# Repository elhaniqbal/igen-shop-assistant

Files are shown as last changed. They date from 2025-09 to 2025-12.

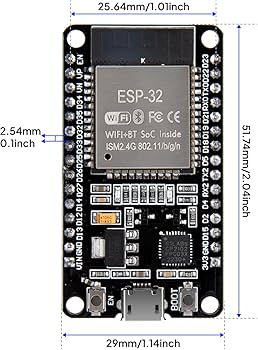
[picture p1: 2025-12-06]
electrical/igen-shop-assistant/ESP32 image.jpg

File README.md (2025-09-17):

# IGEN Smart Shop Assistant — Monorepo Scaffold (v1)

> Raspberry Pi touchscreen/web UI → **Pi Bridge (MQTT↔UART)** → **Controller MCU (ESP32-S3)** → **CAN bus** → **Cabinet MCUs (ESP32-S3)**. Postgres stores users, tools, loans; Mosquitto is the MQTT broker. This repo is an end‑to‑end template with runnable stubs.

---

## 🗂️ Repository Layout

```
igen-shop-assistant/
├─ README.md                            # Start here (you’re reading the in-repo version)
├─ CONTRIBUTING.md
├─ .gitignore
├─ .github/ (LATER DOWN THE ROAD)
│  ├─ workflows/
│  │  ├─ ci.yml                         # Lint, typecheck, build stubs
│  │  └─ pre-commit.yml
│  └─ ISSUE_TEMPLATE.md
├─ docs/
│  ├─ system-overview.md                # Diagrams + deep dives
│  ├─ comms-topology.md                 # MQTT & CAN topics/IDs
│  ├─ onboarding.md                     # Short onboarding for new devs
│  └─ troubleshooting.md
├─ env/
│  ├─ .env.example                      # Copy to .env (root)
│  └─ secrets.template.md
├─ deploy/ (OPTIONAL FOR NOW)
│  ├─ docker-compose.yml                # Mosquitto, Postgres, Adminer, Backend
│  ├─ mosquitto/
│  │  ├─ mosquitto.conf
│  │  └─ aclfile
│  └─ postgres/
│     └─ init.sql                       # DB schema + seed
├─ services/ (RUNS ON RASPBERRY PI)
│  ├─ backend-fastapi/                  # API + events processor (MQTT↔DB)
│  │  ├─ pyproject.toml
│  │  ├─ app/
│  │  │  ├─ main.py                     # FastAPI app
│  │  │  ├─ deps.py                     # DB & MQTT wiring
│  │  │  ├─ models.py                   # SQLModel ORM
│  │  │  ├─ schemas.py                  # Pydantic (JSON/CBOR contracts)
│  │  │  ├─ mqtt_handlers.py            # Subscriptions/handlers
│  │  │  └─ routes/
│  │  │     ├─ admin.py
│  │  │     └─ student.py
│  │  └─ tests/
│  ├─ pi-bridge/                        # Runs on Raspberry Pi (MQTT↔UART)
│  │  ├─ pyproject.toml
│  │  └─ bridge/
│  │     ├─ main.py                     # Sub MQTT, frame CBOR, send over UART
│  │     ├─ uart.py
│  │     └─ framing.py                  # SLIP-like framing + checksum
│  └─ mock-ui-cli/                      # Temporary CLI to simulate the UI
│     ├─ package.json
│     └─ src/
│        └─ index.ts
├─ firmware/
│  ├─ platformio.ini
│  ├─ lib/
│  │  ├─ CanFrame/
│  │  │  ├─ CanFrame.h
│  │  │  └─ CanFrame.cpp
│  │  └─ MsgPack/
│  │     ├─ Msg.h
│  │     └─ Msg.cpp
│  ├─ controller-mcu/                   # ESP32-S3 (UART↔CAN)
│  │  ├─ src/
│  │  │  └─ main.cpp
│  │  └─ include/
│  └─ cabinet-mcu/                      # ESP32-S3 (CAN + IO + sensors)
│     ├─ src/
│     │  └─ main.cpp
│     └─ include/
├─ shared/
│  ├─ schemas/                          # JSON/CBOR schemas with examples
│  │  ├─ mqtt/
│  │  │  ├─ dispense_request.schema.json
│  │  │  ├─ dispense_result.schema.json
│  │  │  ├─ heartbeat.schema.json
│  │  │  └─ sensor_update.schema.json
│  │  └─ can/
│  │     └─ id_format.md                # 11-bit layout + table
│  └─ proto/                            # (optional) for gRPC later
└─ tools/
   ├─ scripts/
   │  ├─ seed_tools.py
   │  └─ gen_test_data.py
   └─ git-templates/
      └─ commit-msg                     # Enforce Conventional Commits
```

---

## 🔐 Branching & Protection (GitHub)

1. **Default branch:** `main`.
2. **Branch naming:** `<your-name>/<type>-<short-desc>` e.g. `elhan/feat-dispense-flow`.
3. **Conventional Commits:** `feat:`, `fix:`, `docs:`, `refactor:`, etc.
4. **Require PR reviews:** At least **1** approval; disallow self-merge.
5. **Require up to date:** Rebase or merge from `main` before merge.

---

## 🧠 System Contracts (Topics, Payloads, CAN IDs)

### MQTT Topic Namespace (broker = Mosquitto)

* Commands from UI/backend → Controller:

  * **`shop/cmd/dispense`** (QoS1): request a dispense action
  * **`shop/cmd/cancel`** (QoS1)
* Controller/MCUs → Backend (events):

  * **`shop/evt/dispense_result`** (QoS1)
  * **`shop/evt/sensor_update`** (QoS0)
  * **`shop/evt/heartbeat`** (QoS0, retain last)
* Device state:

  * **`shop/state/controller`** (retain)
  * **`shop/state/cabinet/{cabinet_id}`** (retain)

> Payloads use **JSON** for human readability during dev; CBOR over **UART** and **CAN** for compactness on microcontrollers.

#### `dispense_request` (JSON)

```json
{
  "request_id": "uuid4",
  "student": { "ubc_card_uid": "hex", "student_id": "string" },
  "items": [ { "tool_id": "uuid", "qty": 1, "slot_id": "CAB01-S05" } ],
  "loan_days": 7,
  "limit_policy": { "max_tools": 3 },
  "requested_at": "2025-09-17T19:00:00Z"
}
```

#### `dispense_result` (JSON)

```json
{
  "request_id": "uuid4",
  "status": "OK | DENIED | PARTIAL | ERROR",
  "details": [ { "slot_id": "CAB01-S05", "result": "OK|JAM|EMPTY" } ],
  "controller_time": "2025-09-17T19:00:01Z"
}
```

#### `heartbeat` (JSON)

```json
{ "device": "controller|cabinet", "id": "CAB01", "ts": "2025-09-17T19:00:00Z", "uptime_s": 1234 }
```

> CBOR equivalents are produced/consumed by Pi Bridge (UART) and MCUs (CAN). See `shared/schemas/` for full drafts.

### CAN ID Layout (11-bit standard)

```
[10..9] Priority (2b)   00=high 01=med 10=low 11=dbg
[8..5]  MsgType  (4b)   0=HB 1=CMD 2=ACK 3=SENS 4=ERR ...
[4..0]  NodeID   (5b)   0=controller, 1..30=cabinets, 31=broadcast
```

**Examples:**

* Broadcast heartbeat from controller: `Prio=10, Type=HB=0x0, Node=0` → `0b10_0000_00000` = `0x200`
* Command to Cabinet #5: `Prio=01, Type=CMD=0x1, Node=0x05` → `0b01_0001_00101` = `0x125`

---

## 🧱 Database (Postgres) — Minimal Schema

`deploy/postgres/init.sql` seeds:

```sql
CREATE EXTENSION IF NOT EXISTS "uuid-ossp";

CREATE TABLE students (
  id UUID PRIMARY KEY DEFAULT uuid_generate_v4(),
  student_id TEXT UNIQUE NOT NULL,
  ubc_card_uid TEXT UNIQUE,
  name TEXT,
  email TEXT,
  created_at TIMESTAMPTZ DEFAULT now()
);

CREATE TABLE tools (
  id UUID PRIMARY KEY DEFAULT uuid_generate_v4(),
  name TEXT NOT NULL,
  sku TEXT,
  description TEXT,
  created_at TIMESTAMPTZ DEFAULT now()
);

CREATE TABLE inventory_slots (
  id TEXT PRIMARY KEY,              -- e.g., CAB01-S05
  cabinet_id TEXT NOT NULL,         -- e.g., CAB01
  tool_id UUID REFERENCES tools(id),
  capacity INT NOT NULL DEFAULT 1,
  qty INT NOT NULL DEFAULT 0,
  sensor_type TEXT,                 -- ir, weight, switch
  created_at TIMESTAMPTZ DEFAULT now()
);

CREATE TABLE loans (
  id UUID PRIMARY KEY DEFAULT uuid_generate_v4(),
  student_id UUID REFERENCES students(id),
  tool_id UUID REFERENCES tools(id),
  slot_id TEXT REFERENCES inventory_slots(id),
  qty INT NOT NULL,
  requested_at TIMESTAMPTZ DEFAULT now(),
  due_at TIMESTAMPTZ NOT NULL,
  returned_at TIMESTAMPTZ
);

CREATE TABLE events (
  id BIGSERIAL PRIMARY KEY,
  kind TEXT NOT NULL,               -- dispense_result, sensor_update, heartbeat
  body JSONB NOT NULL,
  created_at TIMESTAMPTZ DEFAULT now()
);

-- Limits view (example): how many active loans per student
CREATE VIEW active_loan_counts AS
SELECT student_id, COUNT(*) AS active
FROM loans WHERE returned_at IS NULL
GROUP BY student_id;
```

---

## 🐋 Dev Stack (Docker Compose)

`deploy/docker-compose.yml`

```yaml
version: "3.9"
services:
  mqtt:
    image: eclipse-mosquitto:2
    ports: ["1883:1883", "9001:9001"]
    volumes:
      - ./mosquitto/mosquitto.conf:/mosquitto/config/mosquitto.conf
      - ./mosquitto/aclfile:/mosquitto/config/aclfile
  db:
    image: postgres:16
    environment:
      POSTGRES_PASSWORD: postgres
      POSTGRES_USER: postgres
      POSTGRES_DB: shop
    ports: ["5432:5432"]
    volumes:
      - dbdata:/var/lib/postgresql/data
      - ./postgres/init.sql:/docker-entrypoint-initdb.d/init.sql
  adminer:
    image: adminer
    ports: ["8080:8080"]
  backend:
    build: ../services/backend-fastapi
    env_file: ../env/.env
    depends_on: [mqtt, db]
    command: uvicorn app.main:app --host 0.0.0.0 --port 8000
    ports: ["8000:8000"]
volumes:
  dbdata:
```

`deploy/mosquitto/mosquitto.conf`

```conf
listener 1883 0.0.0.0
allow_anonymous true
persistence true
```

---

## 🧩 Backend (FastAPI) — MQTT↔DB glue

`services/backend-fastapi/app/schemas.py`

```python
from pydantic import BaseModel, Field
from typing import List, Literal, Optional
import uuid

class Student(BaseModel):
    ubc_card_uid: str
    student_id: str

class DispenseItem(BaseModel):
    tool_id: str
    qty: int = 1
    slot_id: str

class DispenseRequest(BaseModel):
    request_id: str = Field(default_factory=lambda: str(uuid.uuid4()))
    student: Student
    items: List[DispenseItem]
    loan_days: int = 7
    limit_policy: dict = {"max_tools": 3}

class DispenseDetail(BaseModel):
    slot_id: str
    result: Literal["OK", "JAM", "EMPTY", "DENIED", "ERROR"]

class DispenseResult(BaseModel):
    request_id: str
    status: Literal["OK", "DENIED", "PARTIAL", "ERROR"]
    details: List[DispenseDetail]
```

`services/backend-fastapi/app/main.py`

```python
from fastapi import FastAPI, Depends
from app.schemas import DispenseRequest
from app.mqtt_handlers import publish_dispense

app = FastAPI(title="Shop Assistant Backend")

@app.post("/api/dispense")
def create_dispense(req: DispenseRequest):
    # TODO: validate limits against DB
    publish_dispense(req)
    return {"ok": True, "request_id": req.request_id}
```

`services/backend-fastapi/app/mqtt_handlers.py`

```python
import json, os
import paho.mqtt.client as mqtt
from app.schemas import DispenseRequest

MQTT_HOST = os.getenv("MQTT_HOST", "localhost")
TOPIC_CMD_DISPENSE = "shop/cmd/dispense"

_client = mqtt.Client(mqtt.CallbackAPIVersion.VERSION2)
_client.connect(MQTT_HOST, 1883, 60)

def publish_dispense(req: DispenseRequest):
    _client.publish(TOPIC_CMD_DISPENSE, json.dumps(req.model_dump()), qos=1)
```

---

## 🔗 Pi Bridge (MQTT↔UART, CBOR framing)

`services/pi-bridge/bridge/framing.py`

```python
import cbor2, zlib

START = b"\xC0"  # SLIP-like sentinel

def encode_frame(obj: dict) -> bytes:
    payload = cbor2.dumps(obj)
    crc = zlib.crc32(payload) & 0xFFFFFFFF
    body = payload + crc.to_bytes(4, "big")
    return START + body + START

def decode_frames(buf: bytes):
    # naive splitter for demo
    parts = buf.split(START)
    for i in range(1, len(parts)-1):
        body = parts[i]
        payload, crc = body[:-4], int.from_bytes(body[-4:], "big")
        if zlib.crc32(payload) & 0xFFFFFFFF == crc:
            yield cbor2.loads(payload)
```

`services/pi-bridge/bridge/main.py`

```python
import json, os, serial, threading
import paho.mqtt.client as mqtt
from .framing import encode_frame, decode_frames

MQTT_HOST = os.getenv("MQTT_HOST", "localhost")
UART_PORT = os.getenv("UART_PORT", "/dev/ttyUSB0")
UART_BAUD = int(os.getenv("UART_BAUD", "115200"))

TOPIC_CMD_DISPENSE = "shop/cmd/dispense"
TOPIC_EVT_RESULT   = "shop/evt/dispense_result"

ser = serial.Serial(UART_PORT, UART_BAUD, timeout=0.1)
client = mqtt.Client(mqtt.CallbackAPIVersion.VERSION2)
client.connect(MQTT_HOST, 1883, 60)

# MQTT→UART
def on_message(_c, _ud, msg):
    if msg.topic == TOPIC_CMD_DISPENSE:
        payload = json.loads(msg.payload)
        frame = encode_frame({"t":"DISPENSE", "d": payload})
        ser.write(frame)

client.on_message = on_message
client.subscribe([(TOPIC_CMD_DISPENSE, 1)])
client.loop_start()

# UART→MQTT (controller responses)
rx_buf = bytearray()

def uart_rx_loop():
    while True:
        rx = ser.read(512)
        if rx:
            rx_buf.extend(rx)
            for obj in decode_frames(bytes(rx_buf)):
                if obj.get("t") == "DISPENSE_RESULT":
                    client.publish(TOPIC_EVT_RESULT, json.dumps(obj["d"]))
            # simple: clear buffer on parse attempt
            rx_buf.clear()

threading.Thread(target=uart_rx_loop, daemon=True).start()

print("Pi Bridge running.")
```

---

## 🔧 Firmware — Controller MCU (ESP32-S3, UART↔CAN)

`firmware/platformio.ini`

```ini
[env:esp32s3]
platform = espressif32 @ 6.6.0
board = esp32-s3-devkitc-1
framework = arduino
monitor_speed = 115200
lib_deps =
  adafruit/Adafruit MCP2515 @ ^1.1.0   ; example CAN via MCP2515 if using external transceiver
  bblanchon/ArduinoJson @ ^7
```

`firmware/lib/CanFrame/CanFrame.h`

```cpp
#pragma once
#include <Arduino.h>
struct CanMsg { uint16_t id; uint8_t len; uint8_t data[8]; };
uint16_t makeId(uint8_t prio, uint8_t type, uint8_t node);
```

`firmware/lib/CanFrame/CanFrame.cpp`

```cpp
#include "CanFrame.h"
uint16_t makeId(uint8_t prio, uint8_t type, uint8_t node){
  return ((prio & 0x3) << 9) | ((type & 0xF) << 5) | (node & 0x1F);
}
```

`firmware/controller-mcu/src/main.cpp`

```cpp
#include <Arduino.h>
#include <ArduinoJson.h>
#include "CanFrame.h"

// TODO: init CAN driver (MCP2515 or built-in TWAI for ESP32)

static String rxBuf;

void sendDispenseToCabinet(const JsonObject& req){
  // naive: send one frame per item to its cabinet node
  for (JsonObject item : req["items"].as<JsonArray>()){
    String slot = item["slot_id"].as<String>(); // e.g., CAB01-S05
    uint8_t cabinet = (uint8_t) slot.substring(3,5).toInt(); // "01" -> 1
    uint8_t node = cabinet; // node id mapping

    uint16_t id = makeId(1, /*CMD*/1, node);
    uint8_t data[8] = { 'D','S','P', (uint8_t)item["qty"].as<int>(), 0,0,0,0 };
    // TODO: pack better (CBOR/msgpack)
    // canSend({ .id=id, .len=8, .data={...}});
  }
}

void setup(){
  Serial.begin(115200);
  // canInit();
}

void loop(){
  while (Serial.available()){
    char c = (char)Serial.read();
    rxBuf += c;
    if (c == '\xC0'){
      // demo: parse very simply assuming one JSON frame between 0xC0 sentinels
      int s = rxBuf.indexOf('\xC0');
      int e = rxBuf.lastIndexOf('\xC0');
      if (e > s){
        String body = rxBuf.substring(s+1, e);
        StaticJsonDocument<1024> doc;
        if (deserializeJson(doc, body) == DeserializationError::Ok){
          const char* t = doc["t"];
          if (strcmp(t, "DISPENSE") == 0){
            JsonObject d = doc["d"].as<JsonObject>();
            sendDispenseToCabinet(d);
            // respond minimal result
            StaticJsonDocument<256> res;
            res["t"] = "DISPENSE_RESULT";
            JsonObject dd = res.createNestedObject("d");
            dd["request_id"] = d["request_id"].as<const char*>();
            dd["status"] = "OK";
            serializeJson(res, Serial);
            Serial.write('\xC0');
          }
        }
        rxBuf = "";
      }
    }
  }
  // TODO: forward CAN sensor/heartbeat upstream periodically
}
```

---

## 🔩 Firmware — Cabinet MCU (ESP32-S3, CAN + IO)

`firmware/cabinet-mcu/src/main.cpp`

```cpp
#include <Arduino.h>
#include "CanFrame.h"

const int SOLENOID_PIN = 10; // example
const int IR_PIN = 4;        // example
uint8_t NODE_ID = 1;         // set uniquely per cabinet

void setup(){
  pinMode(SOLENOID_PIN, OUTPUT);
  pinMode(IR_PIN, INPUT_PULLUP);
  // canInit(node=NODE_ID)
}

void loop(){
  // if (canAvailable()){
  //   CanMsg m = canRead();
  //   uint8_t type = (m.id >> 5) & 0xF;
  //   if (type == 1 /*CMD*/){
  //     // naive: data[0..2] == 'D','S','P'
  //     digitalWrite(SOLENOID_PIN, HIGH);
  //     delay(500);
  //     digitalWrite(SOLENOID_PIN, LOW);
  //   }
  // }

  // heartbeat every 2s (pseudo)
  // static uint32_t last=0; if (millis()-last>2000){ sendHB(); last=millis(); }
}
```

---

## 🧪 Mock UI (CLI) — temporary student/admin flows

`services/mock-ui-cli/src/index.ts`

```ts
import mqtt from 'mqtt';
import { randomUUID } from 'crypto';

const client = mqtt.connect('mqtt://localhost:1883');

function sendDispense(studentId: string, cardUid: string, slotId: string, toolId: string){
  const payload = {
    request_id: randomUUID(),
    student: { student_id: studentId, ubc_card_uid: cardUid },
    items: [{ tool_id: toolId, qty: 1, slot_id: slotId }],
    loan_days: 7,
    limit_policy: { max_tools: 3 }
  };
  client.publish('shop/cmd/dispense', JSON.stringify(payload), { qos: 1 });
  console.log('sent dispense', payload);
}

client.on('connect', () => {
  console.log('CLI connected to MQTT');
  sendDispense('s12345678', 'ABCD1234', 'CAB01-S05', 'tool-uuid-1');
});

client.on('message', (t, m) => console.log('evt', t, m.toString()));
client.subscribe('shop/evt/#');
```

---

## 🪪 Card Scanning (abstracted)

On Pi, you can plug a USB NFC reader (ACR122U). Add a `card-reader` module later; for now we provide an **interface** and a **mock** used by the CLI or UI.

Interface (Python):

```python
# services/backend-fastapi/app/card_reader.py
from typing import Optional
class CardReader:
    def get_uid(self) -> Optional[str]:
        """Return hex UID if a card is present else None."""
        raise NotImplementedError

class MockCardReader(CardReader):
    def __init__(self, fixed_uid: str = "ABCD1234"): self.fixed = fixed_uid
    def get_uid(self) -> Optional[str]: return self.fixed
```

---

## 🧭 E2E Flow (What talks to what?)

1. **Student/Admin UI** (web or touchscreen) calls **`POST /api/dispense`** with tool list + card UID.
2. **Backend** validates limits (DB), then publishes **`shop/cmd/dispense`** (JSON).
3. **Pi Bridge** subscribes; converts JSON→CBOR, frames, sends over **UART** to **Controller MCU**.
4. **Controller** parses, maps items → target **Cabinet NodeIDs**, pushes **CMD** frames on **CAN**.
5. **Cabinet MCU** executes (opens solenoid, etc.), optionally reads **IR** to confirm removal, replies via **ACK/SENS**.
6. **Controller** aggregates results → emits **DISPENSE\_RESULT** back over **UART**.
7. **Pi Bridge** publishes **`shop/evt/dispense_result`** (JSON) to MQTT.
8. **Backend** records event & creates **loan** rows (due date = now + loan\_days). Admin notifications (later).

---

## 🚀 Quickstart (Dev)

```bash
# 0) Clone & setup
cp env/.env.example .env
pre-commit install

# 1) Infra
cd deploy && docker compose up -d  # mqtt, postgres, adminer, backend

# 2) Mock UI (simulates student flow)
cd services/mock-ui-cli && npm i && npm run start

# 3) Pi Bridge (if you have a USB-Serial to controller)
cd services/pi-bridge && uv sync && UV_HTTP_TIMEOUT=60 python -m bridge.main
# (set UART_PORT in .env)

# 4) Firmware
# Open `firmware/` in VSCode + PlatformIO, flash controller & a cabinet
```

---

## ✅ Contribution Rules (TL;DR)

* Branch from `main` → name it like `elhan/feat-can-heartbeat`.
* Small PRs with checklists.
* Update `docs/` if you change comms or schemas.
* Add tests where possible (unit tests for handlers, framing, id pack/unpack).
* Keep **topics** and **CAN IDs** in sync with `docs/comms-topology.md`.

---

## 📄 Appendix — Samples & Stubs

**`shared/schemas/mqtt/heartbeat.schema.json`**

```json
{
  "$schema": "https://json-schema.org/draft/2020-12/schema",
  "$id": "https://ubc.example/schemas/heartbeat.json",
  "type": "object",
  "properties": {
    "device": {"enum": ["controller", "cabinet"]},
    "id": {"type": "string"},
    "ts": {"type": "string", "format": "date-time"},
    "uptime_s": {"type": "integer", "minimum": 0}
  },
  "required": ["device", "id", "ts", "uptime_s"]
}
```

**`docs/comms-topology.md`**

```md
# Comms Topology

- UART framing: SLIP-like 0xC0 sentinels, CBOR payload + CRC32.
- CAN: 11-bit IDs (prio|type|node). Data: small msgpack/CBOR blobs.
- Heartbeat: controller every 2s (broadcast), cabinet every 5s.
- Timeouts: dispense op must return within 5s else mark PARTIAL.
```

---

## 🧯 Troubleshooting Cheats

* Nothing on MQTT? `mosquitto_sub -t '#' -v -h localhost`
* UART garbage? Check baud and USB device; ensure `C0` framing matches both sides.
* CAN silent? Verify 120Ω termination at bus ends and common GND.
* DB empty? Open Adminer at [http://localhost:8080](http://localhost:8080) and confirm `tools` seeded.

---

## 📌 Roadmap to v2

* Real NFC reader module (ACR122U) integration on Pi.
* Policy engine for loan limits and overdue alerts.
* Proper CAN driver config (TWAI) and message packing.
* Migrate JSON payloads to CBOR end‑to‑end when UI tooling ready.
* Web UI (Next.js) for Admin/Student dashboards.

```
```

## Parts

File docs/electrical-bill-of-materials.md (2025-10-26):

| Type | Component | Role (what/why) | Qty | Unit est (CAD) | Link (example) |
| --- | --- | --- | ----: | ---: | --- |
| **Static**  | 24 V DC PSU (200–350 W) | Main DC backbone for actuators & logic | 1 | 50 | [MeanWell LRS-350-48](https://www.digikey.ca/en/products/detail/mean-well-usa-inc/LRS-350-48/7705033) |
| **Static**  | IEC inlet w/ switch + fuse | Safe AC entry, master power | 1 | 10 | [uxcell IEC 320 C14](https://www.amazon.ca/uxcell%C2%AE-Terminals-Panel-Socket-Connector/dp/B00HUHAB0U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) |
| **Static**  | EMI line filter | Suppress mains noise | 1 | 10 | [Schaffner FN9222](https://www.digikey.ca/en/products/detail/te-connectivity-schaffner/FN9222-1-06/1928997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) |
| **Static**  | Main breaker/fuse | Overcurrent protection | 1 | 18 | [AWG fuse holder (5pack)](https://www.amazon.ca/gp/product/B0B3J33H38/ref=ox_sc_act_image_1?smid=A3NON9NCBFQHD7&th=1) |
| **Static**  | Terminal Block | Power distribution | 1 set | 15 | [Random Amazon Terminal Block](https://www.amazon.com/Joinfworld-Position-Terminal-Pre-Insulated-Jumper/dp/B0BVR4VY1J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) |
| **Static**  | 24 V TVS diodes | Surge/inductive kick protection | 2 | 4 | [SMBJ24A](https://www.digikey.ca/en/products/detail/littelfuse-inc/SMBJ24A/656394) | |
| **Static**  | Wire + ferrules + glands | Harnessing consumables |  bulk | 25 | [Wire kit](https://www.amazon.ca/582-piece-Electrical-Terminal-Connector-Stripper/dp/B077YZJGQ2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) |
| **Static**  | E-stop switch | Safety cut to PSU | 1 | 12 | [22 mm mushroom NC](https://www.amazon.ca/RuoFeng-Mushroom-Emergency-Button-Switch/dp/B07HBN45Q9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) |
| **Static**  | Branch fuse holders | Per-cabinet protection | n | 15 | [DIN mini fuse](https://www.amazon.ca/KOLACEN-Automotive-Assorted-Circuit-Adapter/dp/B08LTJFBHX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) |
| **Static**  | RFID reader (MFRC522) | User login at kiosk | 1 | 25| [MFRC522 kit](https://leeselectronic.com/en/product/15157-rfid-mifare-rc522-reader-breakout-w-receiver-key.html) |
| **Static**  | RFID chips | IDs for users/tools | 1 | 23| [NTAG213 chips](https://www.amazon.ca/Rewritable-Stickers-Adhesive-Programmable-Compatible/dp/B0C2YW4RM8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) |
| **Dynamic** | 24→5 V buck (3–5 A) | Cabinet logic/sensor rail | n | 13 | [LM2596 buck module](https://www.amazon.ca/Regulator-Adjustable-Converter-Electronic-Stabilizer/dp/B07PDGG84B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) |
| **Dynamic** | CAN transceiver (SN65HVD230) | Node comms to bus | n | 12 | [SN65HVD230 board](https://www.amazon.ca/Waveshare-SN65HVD230-CAN-Board-Communication/dp/B0B5DTN62K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) | | |
| **Dynamic** | Microswitch/IR sensor strip  | Detect slicer | n | 1 | [Micro switch pack](https://www.amazon.ca/Gebildet-pieces-Momentary-Action-V-156-1C25/dp/B07T9DWV4J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) |
| **Static** | Connectors/pigtails | Wiring I/O in cabinet | 1 set | 43 | [JST-VH kit](https://www.amazon.ca/Preciva-Connector-AWG28-18%EF%BC%880-08-1mm%C2%B2-Ratcheting-terminals/dp/B0CH7SB4PC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) |
| **Dynamic** | AS5600 Magnetic Encoder | Angle sensor | n | 6  | [A5600 Encoder](https://www.amazon.ca/Liyquint-Precision-AS5600-Induction-Measurement/dp/B0DQNQTDBT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)
| **Dynamic** | TMC2208 Stepper Driver | Motor Driver for Nema 17 | n | 5  | [TMC2208](https://www.amazon.ca/DKARDU-TMC2208-Adjustable-Screwdriver-Controller/dp/B0CD2CMR65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)

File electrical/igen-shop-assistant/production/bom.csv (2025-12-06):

Designator | Footprint | Quantity | Value | LCSC Part #
24VIN1 | TerminalBlock_Phoenix_MKDS-1,5-2_1x02_P5.00mm_Horizontal | 1 | Conn_01x02 | C8465
AS5600, MOTOR1, SN65HVD230 | PinSocket_1x04_P2.54mm_Horizontal | 3 | Conn_01x04_Socket | C22373928
C1 | 1210 | 1 | 2.2uF | C55151
C2 | 1210 | 1 | 0.1uF | C527381
C3, C8 | 1210 | 2 | 22uF | C309062
C7 | 0603 | 1 | 75pF | C282074
CBOOT2 | 0805 | 1 | 100n | C49678
J1, J2 | PinSocket_1x15_P2.54mm_Vertical | 2 | Conn_01x15_Socket | C41417327
L1 | L_10.4x10.4_H4.8 | 1 | 10uH | C9185
R10 | 0603 | 1 | 100k | C14675
R2 | 0603 | 1 | 511k | C861454
R5 | 0603 | 1 | 105k | C861072
R7 | 0603 | 1 | 2k | C22975
R8 | 0603 | 1 | 22.1k | C25961
R9 | 0603 | 1 | 49.9 | C23185
SWITCH/SENSOR | PinSocket_1x03_P2.54mm_Horizontal | 1 | Conn_01x03_Socket | C22373927
TMC2208_IO1, TMC2208_PWR1 | PinSocket_1x08_P2.54mm_Vertical | 2 | Conn_01x08_Socket | C27438
U1 | SOT-23-6 | 1 | TPS54308 | C168839

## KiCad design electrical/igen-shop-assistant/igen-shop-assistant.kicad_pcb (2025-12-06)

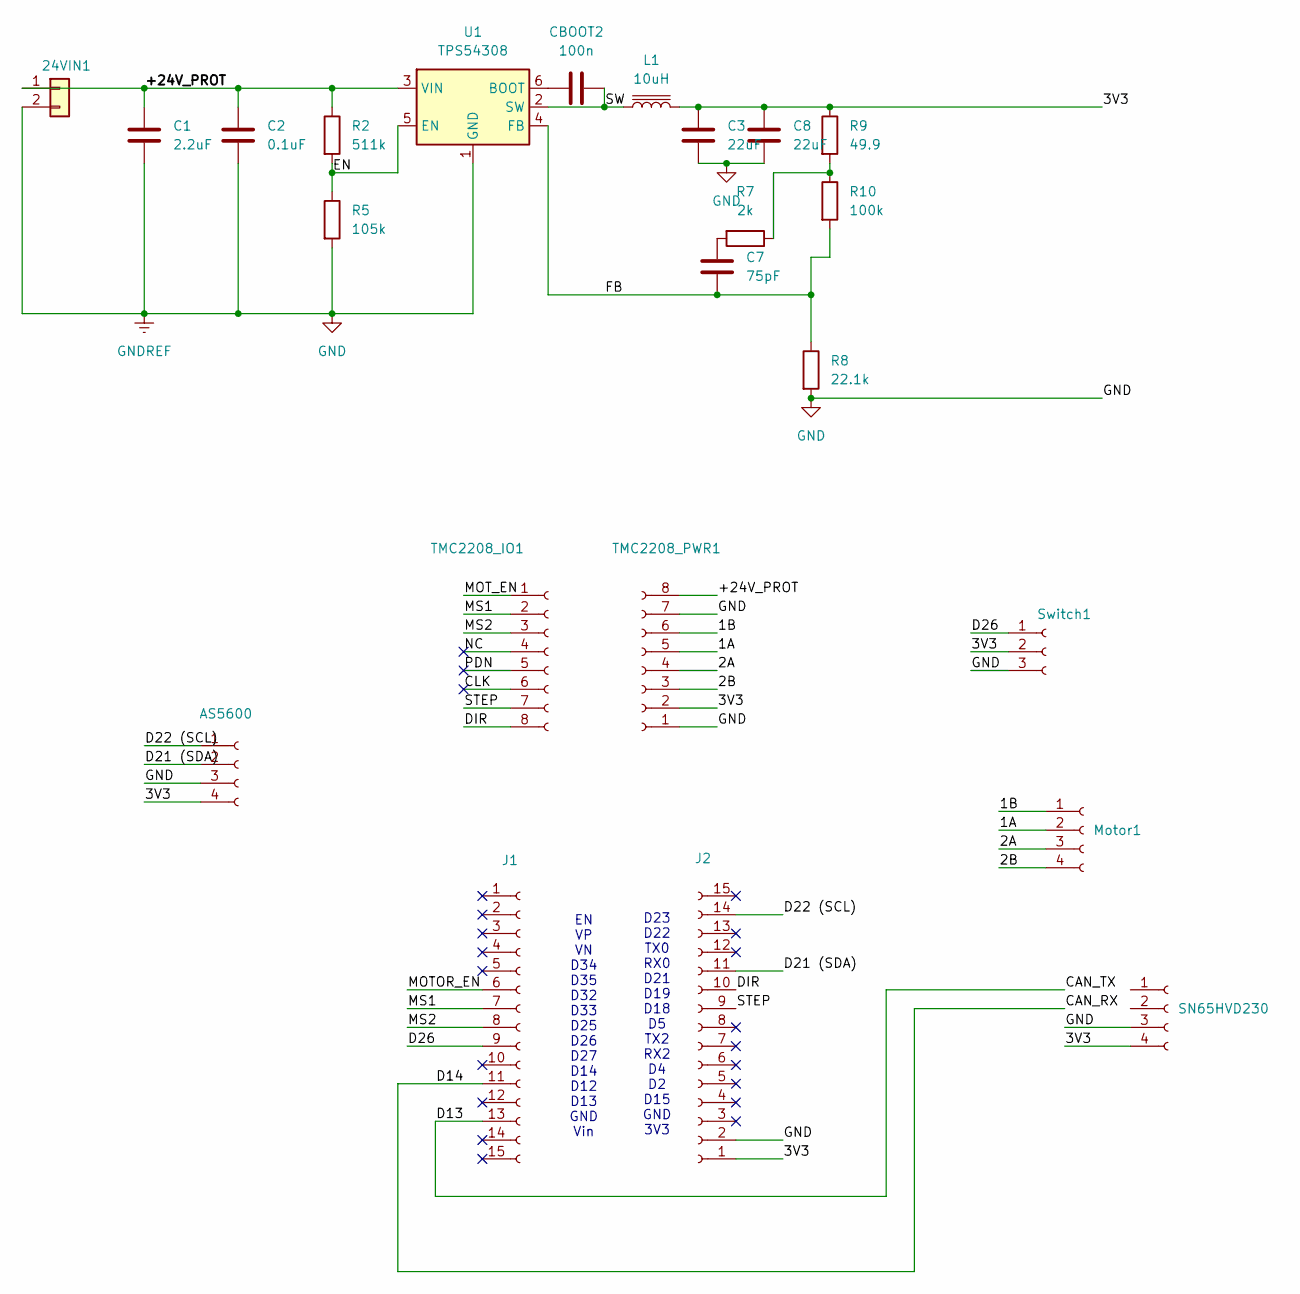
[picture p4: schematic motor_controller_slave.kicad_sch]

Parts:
24VIN1: Conn_01x02; TerminalBlock_Phoenix_MKDS-1,5-2_1x02_P5.00mm_Horizontal; JLCPCB Part Number C8465
AS5600: Conn_01x04_Socket; PinSocket_1x04_P2.54mm_Horizontal; JLCPCB Part Number C22373928
C1: 2.2uF; C_1210_3225Metric; JLCPCB Part Number C55151
C2: 0.1uF; C_1210_3225Metric; JLCPCB Part Number C527381
C3, C8: 22uF; C_1210_3225Metric; JLCPCB Part Number C309062
C7: 75pF; C_0603_1608Metric; JLCPCB Part Number C282074
CBOOT2: 100n; C_0805_2012Metric; JLCPCB Part Number C49678
J1, J2: Conn_01x15_Socket; PinSocket_1x15_P2.54mm_Vertical; JLCPCB Part Number C41417327
L1: 10uH; L_10.4x10.4_H4.8; JLCPCB Part Number C9185
Motor1: Conn_01x04_Socket; PinSocket_1x04_P2.54mm_Horizontal; JLCPCB Part Number C22373928
R2: 511k; R_0603_1608Metric; JLCPCB Part Number C861454
R5: 105k; R_0603_1608Metric; JLCPCB Part Number C861072
R7: 2k; R_0603_1608Metric; JLCPCB Part Number C22975
R8: 22.1k; R_0603_1608Metric; JLCPCB Part Number C25961
R9: 49.9; R_0603_1608Metric; JLCPCB Part Number C23185
R10: 100k; R_0603_1608Metric; JLCPCB Part Number C14675
SN65HVD230: Conn_01x04_Socket; PinSocket_1x04_P2.54mm_Horizontal; JLCPCB Part Number C22373928
Switch1: Conn_01x03_Socket; PinSocket_1x03_P2.54mm_Horizontal; JLCPCB Part Number C22373927
TMC2208_IO1, TMC2208_PWR1: Conn_01x08_Socket; PinSocket_1x08_P2.54mm_Vertical; JLCPCB Part Number C27438
U1: TPS54308; SOT-23-6; JLCPCB Part Number C168839

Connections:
/ESP32+CAN+TMC2208/1A: Motor1.2, TMC2208_PWR1.5
/ESP32+CAN+TMC2208/1B: Motor1.1, TMC2208_PWR1.6
/ESP32+CAN+TMC2208/2A: Motor1.3, TMC2208_PWR1.4
/ESP32+CAN+TMC2208/2B: Motor1.4, TMC2208_PWR1.3
/ESP32+CAN+TMC2208/3V3: AS5600.4, C3.1, C8.1, J2.1, L1.2, R9.1, SN65HVD230.4, Switch1.2, TMC2208_PWR1.2; also elsewhere on the board
/ESP32+CAN+TMC2208/+24V_PROT: 24VIN1.1, C1.1, C2.1, R2.1, TMC2208_PWR1.8, U1.3 (VIN)
/ESP32+CAN+TMC2208/CAN_RX: J1.11
/ESP32+CAN+TMC2208/CAN_TX: J1.13
/ESP32+CAN+TMC2208/CLK: TMC2208_IO1.6
/ESP32+CAN+TMC2208/D21 (SDA): AS5600.2, J2.11
/ESP32+CAN+TMC2208/D22 (SCL): AS5600.1, J2.14
/ESP32+CAN+TMC2208/D26: J1.9, Switch1.1; also elsewhere on the board
/ESP32+CAN+TMC2208/DIR: J2.10, TMC2208_IO1.8
/ESP32+CAN+TMC2208/EN: R2.2, R5.1, U1.5 (EN)
/ESP32+CAN+TMC2208/FB: C7.2, R8.1, R10.2, U1.4 (FB)
/ESP32+CAN+TMC2208/MOTOR_EN: J1.6
/ESP32+CAN+TMC2208/MOT_EN: TMC2208_IO1.1
/ESP32+CAN+TMC2208/MS1: J1.7, TMC2208_IO1.2
/ESP32+CAN+TMC2208/MS2: J1.8, TMC2208_IO1.3
/ESP32+CAN+TMC2208/NC: TMC2208_IO1.4
/ESP32+CAN+TMC2208/PDN: TMC2208_IO1.5
/ESP32+CAN+TMC2208/STEP: J2.9, TMC2208_IO1.7
/ESP32+CAN+TMC2208/SW: CBOOT2.2, L1.1, U1.2 (SW)
GND: 24VIN1.2, AS5600.3, C1.2, C2.2, C3.2, C8.2, J2.2, R5.2, R8.2, SN65HVD230.3, Switch1.3, TMC2208_PWR1.1, TMC2208_PWR1.7, U1.1 (GND); also elsewhere on the board
unnamed: C7.1, R7.2
unnamed: R7.1, R9.2, R10.1
unnamed: CBOOT2.1, U1.6 (BOOT)

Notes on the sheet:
EN VP VN D34 D35 D32 D33 D25 D26 D27 D14 D12 D13 GND Vin
D23 D22 TX0 RX0 D21 D19 D18 D5 TX2 RX2 D4 D2 D15 GND 3V3

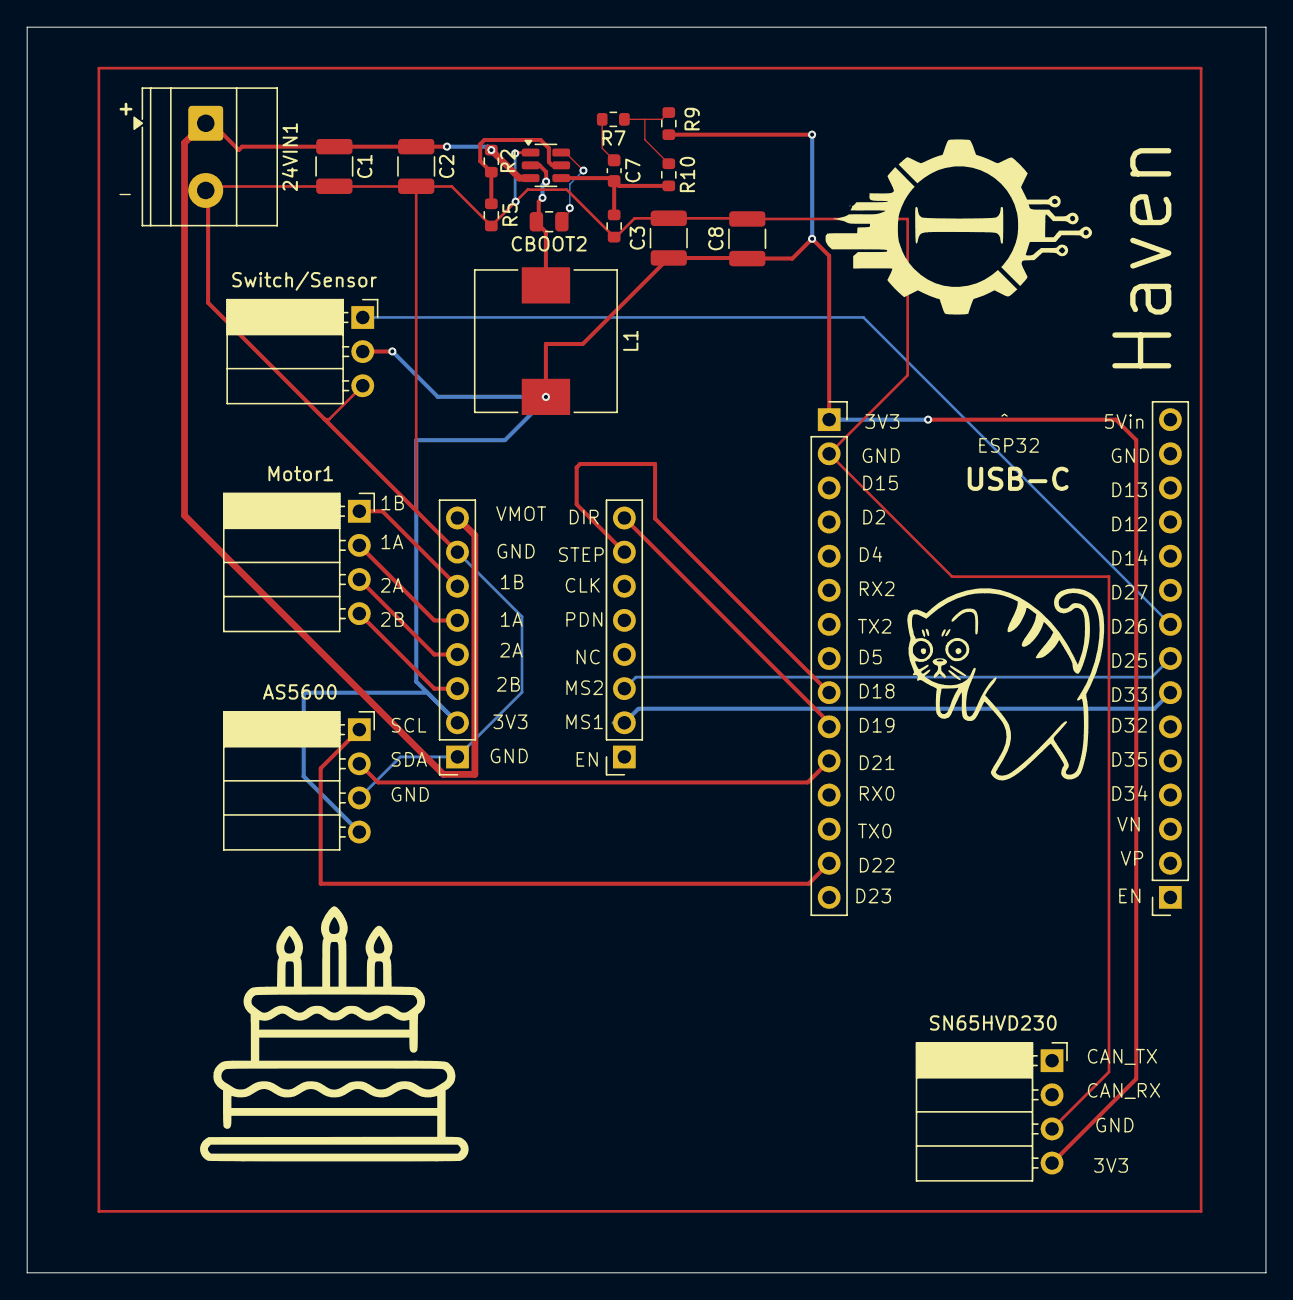
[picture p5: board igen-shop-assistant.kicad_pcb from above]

Board: 2 copper layers, 92.2 x 92.7 mm, 23 parts (0 on the bottom side), 20 nets.

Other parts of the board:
Switch/Sensor: Conn_01x03_Socket; PinSocket_1x03_P2.54mm_Horizontal

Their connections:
/ESP32+CAN+TMC2208/3V3: Switch/Sensor.2; also elsewhere on the board
/ESP32+CAN+TMC2208/D26: Switch/Sensor.1; also elsewhere on the board
GND: Switch/Sensor.3; also elsewhere on the board

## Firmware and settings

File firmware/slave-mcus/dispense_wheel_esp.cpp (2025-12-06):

#include <Arduino.h>
#include <Wire.h>
#include <math.h>
#include <Preferences.h>
#include "driver/twai.h"   // ESP32 CAN (TWAI) driver

// ---------------- Pins ----------------
#define STEP_PIN 18
#define DIR_PIN  19
#define EN_PIN   32
#define MS1_PIN  33
#define MS2_PIN  25

// AS5600 I2C
#define I2C_SDA 21
#define I2C_SCL 22

// CAN pins / node
#define CAN_TX 13
#define CAN_RX 14
#define NODE_ID 3

// ---------------- AS5600 constants ----------------
static const uint8_t AS5600_ADDR      = 0x36;
static const uint8_t REG_RAW_ANGLE_H  = 0x0C;
static const int     TICKS_PER_REV    = 4096;

// Zero ref for single-turn angle (debug)
static uint16_t encZeroRaw = 0;

// ---------------- Motor / gearbox config ----------------
static const int   BASE_STEPS_PER_REV = 200;   // 1.8° motor
int   microstep   = 16;                        // MUST match real driver microstep
int   stepsPerRev = BASE_STEPS_PER_REV * 16;   // 3200 if microstep=16

// GEARBOX: motor revs per 1 wheel rev
static const float GEAR_RATIO = 10.0f;

// high-level speed: WHEEL degrees per second
float degPerSecWheel = 90.0f;

static const uint32_t MIN_US_HALF = 200;
static const bool dirCwHigh       = true;   // DIR=HIGH = CW (flip if wrong)

// ---------------- Drum geometry & inventory ----------------
static const uint8_t DRUM_N    = 5;
static const float   PITCH_DEG = 360.0f / (float)DRUM_N;   // wheel deg per slot

// Default logical state after burn / first boot
//  - slot 0 = open slice at the window
//  - slots array = {0,1,1,1,1}
static const uint8_t DEFAULT_WINDOW_INDEX = 0;

uint8_t slots[DRUM_N] = {0, 1, 1, 1, 1};
uint8_t windowIndex   = DEFAULT_WINDOW_INDEX;   // overridden by NVS

bool modeCwOnly = false;

// ---------------- Encoder multi-turn tracking ----------------
long     multiCounts         = 0;      // total motor counts since startup
uint16_t prevRaw             = 0;
bool     encoderInitialized  = false;

// Tolerances
static const long JAM_TOL_COUNTS          = 300;   // step verification (~26° motor)
static const long MANUAL_MOVE_WARN_COUNTS = 2000;  // manual move detection threshold

// For manual-rotation detection
long baseCountsForIndex   = 0;   // encoder count when windowIndex was last “trusted”
bool baseCountsValid      = false;
unsigned long lastEncPollMs = 0;

// ---------------- Persistence ----------------
Preferences prefs;
static const uint32_t STATE_MAGIC = 0x1A3F5B0C;   // arbitrary constant

// ---------------- CAN / TWAI config ----------------
static bool canOK = false;

static void initCAN() {
  twai_general_config_t g_config = TWAI_GENERAL_CONFIG_DEFAULT(
    (gpio_num_t)CAN_TX,
    (gpio_num_t)CAN_RX,
    TWAI_MODE_NORMAL
  );
  twai_timing_config_t t_config  = TWAI_TIMING_CONFIG_500KBITS();
  twai_filter_config_t f_config  = TWAI_FILTER_CONFIG_ACCEPT_ALL();

  if (twai_driver_install(&g_config, &t_config, &f_config) == ESP_OK) {
    if (twai_start() == ESP_OK) {
      Serial.println(F("[can] TWAI started @500kbps"));
      canOK = true;
    } else {
      Serial.println(F("[can] ERROR: twai_start failed"));
    }
  } else {
    Serial.println(F("[can] ERROR: twai_driver_install failed"));
  }
}

// Receive a single CAN command frame and forward to handleCommand
static void pollCAN() {
  if (!canOK) return;

  twai_message_t msg;
  // Non-blocking receive
  if (twai_receive(&msg, 0) == ESP_OK) {
    Serial.print(F("[can-rx] id=0x"));
    Serial.print(msg.identifier, HEX);
    Serial.print(F(" dlc="));
    Serial.print(msg.data_length_code);
    Serial.print(F(" ext="));
    Serial.print(msg.extd);
    Serial.print(F(" rtr="));
    Serial.print(msg.rtr);
    Serial.print(F(" data=["));
    for (int i = 0; i < msg.data_length_code; ++i) {
      char c = (char)msg.data[i];
      Serial.print((c >= 32 && c <= 126) ? c : '.');
    }
    Serial.println(F("]"));

    // Ignore RTR & extended frames for now
    if (msg.rtr || msg.extd) {
      Serial.println(F("[can-rx] ignoring RTR/ext frame"));
      return;
    }

    if (msg.data_length_code == 0) {
      Serial.println(F("[can-rx] empty frame, ignoring"));
      return;
    }

    String cmd;
    cmd.reserve(msg.data_length_code);
    for (int i = 0; i < msg.data_length_code; ++i) {
      char c = (char)msg.data[i];
      if ((c >= 32 && c <= 126) || c == ' ') {
        cmd += c;
      }
    }
    cmd.trim();

    if (cmd.length() > 0) {
      Serial.print(F("[can] cmd="));
      Serial.println(cmd);
      handleCommand(cmd);   // EXACT same parser as Serial
    } else {
      Serial.println(F("[can-rx] no valid ASCII in frame"));
    }
  }
}

// ---------------- Small helpers ----------------
static inline uint8_t modN(int v) {
  int m = v % (int)DRUM_N;
  return (m < 0) ? (m + DRUM_N) : m;
}

// ---------------- AS5600 helpers ----------------
static uint16_t i2cRead16(uint8_t dev, uint8_t regHigh) {
  Wire.beginTransmission(dev);
  Wire.write(regHigh);
  if (Wire.endTransmission(false) != 0) return 0;
  if (Wire.requestFrom((int)dev, 2) != 2) return 0;
  uint8_t hi = Wire.read();
  uint8_t lo = Wire.read();
  return ((uint16_t)hi << 8) | lo;
}

static uint16_t as5600AngleRaw() {
  uint16_t raw = i2cRead16(AS5600_ADDR, REG_RAW_ANGLE_H);
  return raw & 0x0FFF;
}

// Single-turn MOTOR angle for debug [0..360)
static float encoderMotorAngleDegSingleTurn() {
  uint16_t raw = as5600AngleRaw();
  int32_t diff = (int32_t)raw - (int32_t)encZeroRaw;
  if (diff < 0) diff += TICKS_PER_REV;
  if (diff >= TICKS_PER_REV) diff -= TICKS_PER_REV;
  float deg = (diff * 360.0f) / (float)TICKS_PER_REV;
  if (deg >= 360.0f) deg -= 360.0f;
  return deg;
}

// Multi-turn update (call routinely + while motor is moving)
static long updateEncoderMulti() {
  uint16_t raw = as5600AngleRaw();

  if (!encoderInitialized) {
    prevRaw = raw;
    encoderInitialized = true;
    return 0;
  }

  int32_t delta = (int32_t)raw - (int32_t)prevRaw;

  // Wrap correction: half-turn = 2048 counts
  if (delta >  2048) delta -= 4096;
  if (delta < -2048) delta += 4096;

  multiCounts += delta;
  prevRaw = raw;
  return delta;
}

// ---------------- Microstepping ----------------
static void applyMicrostepPins() {
  pinMode(MS1_PIN, OUTPUT);
  pinMode(MS2_PIN, OUTPUT);

  bool ms1 = LOW;
  bool ms2 = LOW;

  switch (microstep) {
    case 1:   ms1 = LOW;  ms2 = LOW;  break;
    case 2:   ms1 = HIGH; ms2 = LOW;  break;
    case 4:   ms1 = LOW;  ms2 = HIGH; break;
    case 8:   ms1 = HIGH; ms2 = HIGH; break;
    case 16:  ms1 = HIGH; ms2 = HIGH; break;
    default:  ms1 = LOW;  ms2 = LOW;  break;
  }

  digitalWrite(MS1_PIN, ms1);
  digitalWrite(MS2_PIN, ms2);
}

static bool setMicrostep(int m) {
  if (m != 1 && m != 2 && m != 4 && m != 8 && m != 16) {
    Serial.println(F("[cfg] invalid microstep (use 1,2,4,8,16)"));
    return false;
  }
  microstep   = m;
  stepsPerRev = BASE_STEPS_PER_REV * microstep;
  applyMicrostepPins();
  Serial.print(F("[cfg] microstep="));
  Serial.print(microstep);
  Serial.print(F(" stepsPerRev="));
  Serial.println(stepsPerRev);
  return true;
}

// ---------------- Persistence (windowIndex only) ----------------
static void saveState() {
  prefs.putUInt("magic", STATE_MAGIC);
  prefs.putUChar("slot", windowIndex);
  Serial.print(F("[state] saved windowIndex="));
  Serial.println(windowIndex);
}

static void loadState() {
  prefs.begin("wheel", false);
  uint32_t magic = prefs.getUInt("magic", 0);

  if (magic == STATE_MAGIC) {
    windowIndex = prefs.getUChar("slot", DEFAULT_WINDOW_INDEX);
    Serial.print(F("[state] loaded windowIndex="));
    Serial.println(windowIndex);
  } else {
    Serial.println(F("[state] no valid state, seeding defaults"));
    windowIndex = DEFAULT_WINDOW_INDEX;
    prefs.putUInt("magic", STATE_MAGIC);
    prefs.putUChar("slot", windowIndex);
    Serial.print(F("[state] default windowIndex="));
    Serial.println(windowIndex);
  }

  // After load, treat current encoder position as base for that index
  baseCountsForIndex = multiCounts;
  baseCountsValid    = true;
}

// Wipe stored state and reset to default idx=0 (open slice)
static void burnState() {
  prefs.begin("wheel", false);
  Serial.println(F("[state] WARNING: clearing stored state and resetting to defaults..."));

  prefs.clear();

  windowIndex = DEFAULT_WINDOW_INDEX;
  prefs.putUInt("magic", STATE_MAGIC);
  prefs.putUChar("slot", windowIndex);

  baseCountsForIndex = multiCounts;   // whatever angle we’re at now = “slot 0 open”
  baseCountsValid    = true;

  Serial.print(F("[state] EEPROM reset to default windowIndex="));
  Serial.println(windowIndex);
}

// ---------------- Stepper motion (MOTOR space) ----------------

static void moveSteps(long steps, bool cw) {
  if (steps <= 0) return;

  // set direction once
  digitalWrite(DIR_PIN, cw == dirCwHigh ? HIGH : LOW);

  // convert wheel deg/s to motor steps/s
  float motorDegPerSec = degPerSecWheel * GEAR_RATIO;
  float sps = (motorDegPerSec * stepsPerRev) / 360.0f;
  if (sps < 100.0f) sps = 100.0f;
  float period_us = 1e6f / sps;
  uint32_t usHalf = (uint32_t)max((float)MIN_US_HALF, period_us / 2.0f);

  for (long i = 0; i < steps; ++i) {
    digitalWrite(STEP_PIN, HIGH);
    delayMicroseconds(usHalf);
    digitalWrite(STEP_PIN, LOW);
    delayMicroseconds(usHalf);

    // Update encoder multi-turn tracking per step
    updateEncoderMulti();
  }
}

// Low-level motor movement in MOTOR degrees, with encoder verification
static bool moveMotorByDegreesVerified(float deltaMotorDeg) {
  // Make sure encoder tracking is fresh
  updateEncoderMulti();

  // ---- Detect manual rotation since last trusted index ----
  if (baseCountsValid && digitalRead(EN_PIN) == HIGH) {
    long diffCounts = multiCounts - baseCountsForIndex;
    if (labs(diffCounts) > MANUAL_MOVE_WARN_COUNTS) {
      float motorIdleDeg = diffCounts * 360.0f / (float)TICKS_PER_REV;
      float wheelIdleDeg = motorIdleDeg / GEAR_RATIO;
      float slotsIdle    = wheelIdleDeg / PITCH_DEG;

      Serial.print(F("[WARN] detected manual rotation since last index align: ~"));
      Serial.print(wheelIdleDeg, 1);
      Serial.print(F(" wheel deg (~"));
      Serial.print(slotsIdle, 2);
      Serial.println(F(" slots). Logical index may be wrong."));
      // We do NOT touch windowIndex here.
    }
  }

  // ---- Normal commanded move verification ----
  if (!isfinite(deltaMotorDeg) || fabsf(deltaMotorDeg) < 0.1f) return true;

  bool cw      = (deltaMotorDeg > 0.0f);
  float absDeg = fabsf(deltaMotorDeg);

  long steps = lroundf((absDeg * stepsPerRev) / 360.0f);
  if (steps <= 0) return true;

  // Expected encoder counts for this move
  long expectedCounts = lroundf(deltaMotorDeg * (float)TICKS_PER_REV / 360.0f);

  Serial.print(F("[move] motor "));
  Serial.print(deltaMotorDeg, 2);
  Serial.print(F(" deg -> "));
  Serial.print(steps);
  Serial.print(F(" steps, expectedCounts="));
  Serial.println(expectedCounts);

  long startCounts = multiCounts;

  // Enable driver only while moving
  digitalWrite(EN_PIN, LOW);
  delay(2);

  moveSteps(steps, cw);

  digitalWrite(EN_PIN, HIGH); // disable after move

  long actualCounts = multiCounts - startCounts;
  long errorCounts  = actualCounts - expectedCounts;

  Serial.print(F("[enc] actualCounts="));
  Serial.print(actualCounts);
  Serial.print(F(" error="));
  Serial.println(errorCounts);

  if (labs(errorCounts) > JAM_TOL_COUNTS) {
    Serial.println(F("[FAULT] encoder mismatch: motor did NOT move as commanded"));
    return false;
  }

  Serial.println(F("[OK] encoder verified move"));
  return true;
}

// High-level movement in WHEEL degrees
static bool moveWheelByDegreesVerified(float deltaWheelDeg) {
  float deltaMotorDeg = deltaWheelDeg * GEAR_RATIO;
  return moveMotorByDegreesVerified(deltaMotorDeg);
}

// ---------------- Index / geometry ----------------
static void advanceIndexCW(uint8_t steps) {
  windowIndex = modN((int)windowIndex + (int)steps);
}

static void advanceIndexCCW(uint8_t steps) {
  windowIndex = modN((int)windowIndex - (int)steps);
}

// Compute how many slot steps and direction to go from windowIndex to target
static void computeMove(uint8_t target, uint8_t &stepsOut, bool &cwOut) {
  int cwSteps  = modN((int)target - (int)windowIndex);  // + direction on WHEEL
  int ccwSteps = modN((int)windowIndex - (int)target);  // - direction on WHEEL

  if (modeCwOnly) {
    stepsOut = (uint8_t)cwSteps;
    cwOut    = true;
  } else {
    if (cwSteps <= ccwSteps) {
      stepsOut = (uint8_t)cwSteps;
      cwOut    = true;
    } else {
      stepsOut = (uint8_t)ccwSteps;
      cwOut    = false;
    }
  }
}

static bool rotateToSlot(uint8_t target) {
  uint8_t steps;
  bool cw;
  computeMove(target, steps, cw);
  if (steps == 0) return true;

  float deltaWheelDeg = (float)steps * PITCH_DEG * (cw ? +1.0f : -1.0f);

  bool ok = moveWheelByDegreesVerified(deltaWheelDeg);
  if (!ok) {
    Serial.println(F("[geo] move FAILED, not updating index/state"));
    return false;
  }

  if (cw) advanceIndexCW(steps);
  else    advanceIndexCCW(steps);

  Serial.print(F("[geo] windowIndex -> "));
  Serial.println(windowIndex);

  // After a successful logical index change, re-anchor encoder
  baseCountsForIndex = multiCounts;
  baseCountsValid    = true;

  saveState();
  return true;
}

// ---------------- Inventory ----------------
static void printSlots() {
  Serial.print(F("[slots] idx="));
  Serial.print(windowIndex);
  Serial.print(F(" state=["));
  for (uint8_t i = 0; i < DRUM_N; ++i) {
    Serial.print((int)slots[i]);
    if (i + 1 < DRUM_N) Serial.print(',');
  }
  Serial.println(']');
}

static int8_t findNearestFilled() {
  int bestSteps = 999;
  int bestIdx   = -1;

  for (uint8_t i = 0; i < DRUM_N; ++i) {
    if (i == 0) continue;          // never use slot 0
    if (slots[i] != 1) continue;   // only filled slots

    int cwSteps  = modN((int)i - (int)windowIndex);
    int ccwSteps = modN((int)windowIndex - (int)i);
    int steps = modeCwOnly
      ? cwSteps
      : (cwSteps <= ccwSteps ? cwSteps : ccwSteps);

    if (steps > 0 && steps < bestSteps) {
      bestSteps = steps;
      bestIdx   = i;
    }
  }
  return (int8_t)bestIdx;
}

void sendCanAck(const String &msg) {
  twai_message_t tx = {};
  tx.identifier = NODE_ID;       // 3
  tx.extd = 0;
  tx.rtr  = 0;
  tx.data_length_code = msg.length();

  for (int i = 0; i < msg.length() && i < 8; i++) {
    tx.data[i] = msg[i];
  }

  if (twai_transmit(&tx, pdMS_TO_TICKS(20)) == ESP_OK) {
    Serial.print("[ack] sent: "); Serial.println(msg);
  } else {
    Serial.println("[ack] FAILED to send");
  }
}


// nearest empty CCW (including slot 0)
static int8_t findNearestEmptyCCW() {
  for (int step = 1; step < DRUM_N; ++step) {
    uint8_t idx = modN((int)windowIndex - step);
    if (slots[idx] == 0) {
      return (int8_t)idx;
    }
  }
  return -1;
}

static bool performDispense() {
  int8_t idx = findNearestFilled();
  if (idx < 0) {
    Serial.println(F("[disp] no filled slots available"));
    return false;
  }

  Serial.print(F("[disp] target slot "));
  Serial.println(idx);

  if (!rotateToSlot((uint8_t)idx)) {
    Serial.println(F("[disp] ABORT: rotation failed"));
    return false;
  }

  // Dispensed from windowIndex
  slots[windowIndex] = 0;
  printSlots();
  return true;
}

static bool performReturn() {
  Serial.println(F("[ret] docking hold..."));
  delay(2000);

  if (windowIndex == 0) {
    Serial.println(F("[ret] ERROR: cannot return into slot 0 (non-storage)."));
    return false;
  }

  // Deposit into current slot
  slots[windowIndex] = 1;

  // Find new open slot CCW
  int8_t idx = findNearestEmptyCCW();
  if (idx < 0) {
    Serial.println(F("[ret] no empty slots available after return"));
    printSlots();
    return false;
  }

  Serial.print(F("[ret] new open slot (CCW) = "));
  Serial.println(idx);

  int steps = modN((int)windowIndex - (int)idx);
  if (steps <= 0) {
    printSlots();
    saveState();
    return true;
  }

  float deltaWheelDeg = - (float)steps * PITCH_DEG;
  bool ok = moveWheelByDegreesVerified(deltaWheelDeg);
  if (!ok) {
    Serial.println(F("[ret] ABORT: rotation failed, not updating index"));
    return false;
  }

  advanceIndexCCW((uint8_t)steps);

  // Re-anchor encoder after successful move
  baseCountsForIndex = multiCounts;
  baseCountsValid    = true;

  printSlots();
  saveState();
  return true;
}

// ---------------- Serial & CAN commands ----------------
static void printHelp() {
  Serial.println(F("Commands (via Serial or CAN data bytes):"));
  Serial.println(F("  help          - show this help"));
  Serial.println(F("  angle         - show MOTOR single-turn angle [0..360)"));
  Serial.println(F("  zero          - set current MOTOR position as 0 deg"));
  Serial.println(F("  deg <angle>   - move WHEEL RELATIVE by <angle> deg (+CW, -CCW)"));
  Serial.println(F("  spd <dps>     - set WHEEL speed in deg/s"));
  Serial.println(F("  ms <1|2|4|8|16> - set microstepping"));
  Serial.println(F("  slots         - show slot state & window index"));
  Serial.println(F("  disp          - perform dispense to nearest filled slot"));
  Serial.println(F("  ret           - perform return to nearest empty slot"));
  Serial.println(F("  mode bi       - bidirectional (shortest path)"));
  Serial.println(F("  mode cw       - CW-only rotation"));
  Serial.println(F("  burn          - CLEAR saved state and reset to default (idx=0)"));
}

void handleCommand(String cmd) {
  cmd.trim();
  if (cmd.length() == 0) return;
  String low = cmd;
  low.toLowerCase();

  if (low == "help") { printHelp(); return; }

  if (low == "angle") {
    float a = encoderMotorAngleDegSingleTurn();
    Serial.print(F("[enc] MOTOR angle(single-turn) = "));
    Serial.print(a, 2);
    Serial.println(F(" deg"));
    return;
  }

  if (low == "zero") {
    encZeroRaw = as5600AngleRaw();
    Serial.print(F("[enc] zero set at raw="));
    Serial.println(encZeroRaw);
    return;
  }

  if (low.startsWith("deg ")) {
    float wheelDeg = cmd.substring(4).toFloat();
    moveWheelByDegreesVerified(wheelDeg);
    return;
  }

  if (low.startsWith("spd ")) {
    float s = cmd.substring(4).toFloat();
    if (s > 0.1f) {
      degPerSecWheel = s;
      Serial.print(F("[cfg] wheel speed="));
      Serial.println(degPerSecWheel, 1);
    } else {
      Serial.println(F("[cfg] speed must be >0"));
    }
    return;
  }

  if (low.startsWith("ms ")) {
    int m = cmd.substring(3).toInt();
    setMicrostep(m);
    return;
  }

  if (low == "slots") {
    printSlots();
    return;
  }

  if (low == "disp") {
     bool ok = performDispense();
    if (ok) sendCanAck("ack:disp");
    else    sendCanAck("err:disp");
    return;
  }

  if (low == "ret") {
    bool ok = performReturn();
    if (ok) sendCanAck("ack:return");
    else    sendCanAck("err:return");
    return;
  }

  if (low == "mode bi") {
    modeCwOnly = false;
    Serial.println(F("[mode] bidirectional (shortest path)"));
    return;
  }

  if (low == "mode cw") {
    modeCwOnly = true;
    Serial.println(F("[mode] CW-only"));
    return;
  }

  if (low == "burn") {
    burnState();
    return;
  }

  Serial.print(F("[err] unknown command '"));
  Serial.print(cmd);
  Serial.println(F("'; type 'help'"));
}

// ---------------- Arduino hooks ----------------
void setup() {
  Serial.begin(115200);
  delay(200);

  pinMode(EN_PIN, OUTPUT);
  pinMode(STEP_PIN, OUTPUT);
  pinMode(DIR_PIN, OUTPUT);
  digitalWrite(STEP_PIN, LOW);
  digitalWrite(DIR_PIN, LOW);
  digitalWrite(EN_PIN, HIGH); // disabled by default (active-low)

  Wire.begin(I2C_SDA, I2C_SCL);
  Wire.setClock(400000);

  applyMicrostepPins();
  encZeroRaw = as5600AngleRaw();
  prevRaw    = as5600AngleRaw();
  encoderInitialized = true;
  multiCounts = 0;

  // Initial base anchor is “whatever angle we booted at”
  baseCountsForIndex = multiCounts;
  baseCountsValid    = true;

  loadState();
  initCAN();

  Serial.println(F("ESP32 drum test: gearbox + encoder-verified moves + manual-move warning + CAN RX"));
  Serial.print(F("BASE_STEPS_PER_REV="));
  Serial.println(BASE_STEPS_PER_REV);
  Serial.print(F("microstep="));
  Serial.println(microstep);
  Serial.print(F("stepsPerRev="));
  Serial.println(stepsPerRev);
  Serial.print(F("GEAR_RATIO="));
  Serial.println(GEAR_RATIO, 2);
  Serial.print(F("Initial encZeroRaw="));
  Serial.println(encZeroRaw);
  printSlots();
  printHelp();
}

void loop() {
  // Periodic encoder polling to track manual motion smoothly
  unsigned long now = millis();
  if (now - lastEncPollMs >= 20) {   // 50 Hz
    lastEncPollMs = now;
    updateEncoderMulti();
  }

  // Serial commands
  if (Serial.available()) {
    String cmd = Serial.readStringUntil('\n');
    handleCommand(cmd);
  }

  // CAN commands
  pollCAN();
}

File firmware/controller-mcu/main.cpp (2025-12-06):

// controller-mcu/main.cpp
//
// ESP32 Controller MCU
// - Bridges upstream (MQTT preferred, UART fallback) <-> CAN(TWAI) slaves
// - Forwards commands and replies, periodically polls status
//
#include <Arduino.h>
#include <WiFi.h>
#include <PubSubClient.h>
#include <ArduinoJson.h>
#include "driver/twai.h"
#include "protocol.h"

// -------- Build-time config (can be overridden in platformio.ini) --------
#ifndef WIFI_SSID
#define WIFI_SSID "ssid"
#endif
#ifndef WIFI_PASS
#define WIFI_PASS "pass"
#endif
#ifndef MQTT_HOST
#define MQTT_HOST "192.168.1.50"
#endif
#ifndef MQTT_PORT
#define MQTT_PORT 1883
#endif
#ifndef MQTT_CLIENT_ID
#define MQTT_CLIENT_ID "igen-controller"
#endif
#ifndef CAN_TX_PIN
#define CAN_TX_PIN 27
#endif
#ifndef CAN_RX_PIN
#define CAN_RX_PIN 26
#endif
#ifndef CAN_BPS
#define CAN_BPS 500000
#endif
#ifndef UART_TX_PIN
#define UART_TX_PIN 17
#endif
#ifndef UART_RX_PIN
#define UART_RX_PIN 16
#endif

// Known node IDs to poll (edit as you add modules)
static uint8_t KNOWN_IDS[] = { 4 /*wheel*/, 7 /*gantry*/ };
static const size_t KNOWN_N = sizeof(KNOWN_IDS) / sizeof(KNOWN_IDS[0]);

// -------- Globals --------
WiFiClient net;
PubSubClient mqtt(net);
HardwareSerial UPLINK(1);   // UART1 to Raspberry Pi (or other host)

enum class UpMode { UART_ONLY, MQTT_PREFERRED };
UpMode upMode = UpMode::UART_ONLY;

unsigned long lastMqttCheck = 0;
unsigned long lastPoll = 0;

// -------- CAN(TWAI) helpers --------
static void canStart() {
  twai_general_config_t g =
      TWAI_GENERAL_CONFIG_DEFAULT((gpio_num_t)CAN_TX_PIN, (gpio_num_t)CAN_RX_PIN, TWAI_MODE_NORMAL);

  twai_timing_config_t t;
#if   (CAN_BPS == 1000000)
  t = TWAI_TIMING_CONFIG_1MBITS();
#elif (CAN_BPS == 800000)
  t = TWAI_TIMING_CONFIG_800KBITS();
#elif (CAN_BPS == 500000)
  t = TWAI_TIMING_CONFIG_500KBITS();
#elif (CAN_BPS == 250000)
  t = TWAI_TIMING_CONFIG_250KBITS();
#elif (CAN_BPS == 125000)
  t = TWAI_TIMING_CONFIG_125KBITS();
#else
# error Unsupported CAN_BPS. Use 1M/800k/500k/250k/125k.
#endif

  twai_filter_config_t f = TWAI_FILTER_CONFIG_ACCEPT_ALL();
  ESP_ERROR_CHECK(twai_driver_install(&g, &t, &f));
  ESP_ERROR_CHECK(twai_start());
}

static bool canSend(uint16_t id, const uint8_t* data, uint8_t len) {
  twai_message_t tx = {};
  tx.identifier = id;
  tx.extd = 0;
  tx.rtr = 0;
  uint8_t dlc = (len > 8) ? 8 : len;
  tx.data_length_code = dlc;
  if (dlc > 0 && data) memcpy(tx.data, data, dlc);
  return twai_transmit(&tx, pdMS_TO_TICKS(50)) == ESP_OK;
}

static bool canWaitReply(uint16_t replyId, twai_message_t& out, uint32_t timeout_ms = 400) {
  uint32_t until = millis() + timeout_ms;
  while (millis() < until) {
    twai_message_t rx;
    if (twai_receive(&rx, pdMS_TO_TICKS(20)) == ESP_OK) {
      if (!rx.extd && rx.identifier == replyId) { out = rx; return true; }

      // Forward unsolicited status upstream
      if (!rx.extd && rx.identifier >= 100 && rx.identifier < 128) {
        uint8_t dev = rx.identifier - 100;
        if (rx.data_length_code > 0 && rx.data[0] == R_STATUS) {
          JsonDocument dj;
          dj["src"]  = "status";
          dj["id"]   = dev;
          dj["code"] = rx.data[0];
          if (rx.data_length_code > 1) dj["b1"] = rx.data[1];
          if (rx.data_length_code > 2) dj["b2"] = rx.data[2];
          if (rx.data_length_code > 3) dj["b3"] = rx.data[3];

          char buf[160];
          size_t n = serializeJson(dj, buf, sizeof(buf));
          if (upMode == UpMode::MQTT_PREFERRED && mqtt.connected()) {
            char topic[64]; snprintf(topic, sizeof(topic), "igen/slave/%u/status", dev);
            mqtt.publish(topic, buf, n);
          } else {
            UPLINK.write((const uint8_t*)buf, n);
            UPLINK.write('\n');
          }
        }
      }
    }
  }
  return false;
}

// -------- Upstream helpers --------
static void sendUp(const JsonDocument& d, const char* topicLeaf = nullptr) {
  if (upMode == UpMode::MQTT_PREFERRED && mqtt.connected()) {
    String topic = String("igen/controller/") + (topicLeaf ? topicLeaf : "event");
    String payload; serializeJson(d, payload);
    mqtt.publish(topic.c_str(), payload.c_str());
  } else {
    String line; serializeJson(d, line);
    UPLINK.println(line);
  }
}

static void applyCommand(const JsonDocument& jd) {
  const char* cmd = jd["cmd"] | "";
  uint8_t id = jd["id"] | 0;

  // Broadcast poll
  if (id == 0 && strcmp(cmd, "get_status") == 0) {
    for (size_t i = 0; i < KNOWN_N; i++) {
      uint8_t tid = KNOWN_IDS[i];
      uint8_t b[1] = { OP_GET_STATUS };
      canSend(tid, b, 1);
    }
    return;
  }
  if (id == 0) return; // need a target id otherwise

  uint8_t b[8] = {0};
  uint8_t len = 0;

  if      (!strcmp(cmd, "dispense_nearest")) { b[0] = OP_DISPENSE_NEAREST; len = 1; }
  else if (!strcmp(cmd, "return_nearest"))   { b[0] = OP_RETURN_NEAREST;   len = 1; }
  else if (!strcmp(cmd, "set_zero"))         { b[0] = OP_SET_ZERO_HERE;    len = 1; }
  else if (!strcmp(cmd, "dispense_to_slot")) { b[0] = OP_DISPENSE_TO_SLOT; b[1] = (uint8_t)(jd["slot"] | 0); len = 2; }
  else if (!strcmp(cmd, "get_status"))       { b[0] = OP_GET_STATUS;       len = 1; }
  else if (!strcmp(cmd, "set_slot"))         { b[0] = OP_SET_SLOT; b[1] = (uint8_t)(jd["slot"] | 0); b[2] = (uint8_t)((jd["filled"] | 0) ? 1 : 0); len = 3; }
  else if (!strcmp(cmd, "set_param")) {
    b[0] = OP_SET_PARAM;
    b[1] = (uint8_t)(jd["sub"] | 0);
    len  = 2;
    if (jd["u16"].is<unsigned>()) {
      uint16_t v = (uint16_t)jd["u16"].as<unsigned>();
      pack_u16_be(&b[2], v); len = 4;
    } else if (jd["u8"].is<unsigned>()) {
      b[2] = (uint8_t)jd["u8"].as<unsigned>(); len = 3;
    } else if (jd["f"].is<float>()) {
      float f = jd["f"].as<float>(); pack_float(&b[2], f); len = 6;
    }
  } else {
    return; // unknown command
  }

  JsonDocument out;
  out["type"] = "reply";
  out["to"]   = id;
  out["sent"] = b[0];

  bool ok = canSend(id, b, len);
  if (!ok) { out["err"] = "CAN_TX"; sendUp(out, "error"); return; }

  twai_message_t rx;
  if (canWaitReply(100 + id, rx, 600)) {
    out["code"] = rx.data[0];
    JsonArray arr = out["data"].to<JsonArray>();
    for (int i = 1; i < rx.data_length_code; i++) arr.add(rx.data[i]);
    sendUp(out, "rx");
  } else {
    out["err"] = "TIMEOUT";
    sendUp(out, "timeout");
  }
}

static void onMqttMessage(char* topic, byte* payload, unsigned int length) {
  JsonDocument jd;
  DeserializationError e = deserializeJson(jd, payload, length);
  if (!e) applyCommand(jd);
}

static void mqttEnsure() {
  if (mqtt.connected()) return;
  if (WiFi.status() != WL_CONNECTED) return;

  mqtt.setServer(MQTT_HOST, MQTT_PORT);
  mqtt.setCallback(onMqttMessage);

  if (mqtt.connect(MQTT_CLIENT_ID)) {
    mqtt.subscribe("igen/controller/cmd");
    upMode = UpMode::MQTT_PREFERRED;
    JsonDocument dj; dj["type"] = "online";
    sendUp(dj, "lifecycle");
  }
}
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

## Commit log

2025-09-24 Initial BOM
2025-10-15 added wheel logic static test site and updated docker compose
2025-10-26 updated BOM
2025-12-06 Added electrical schematic
    [bom.csv, designators.csv, gantry.kicad_sch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]
